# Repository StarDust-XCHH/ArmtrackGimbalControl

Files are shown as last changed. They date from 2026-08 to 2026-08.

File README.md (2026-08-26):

# ArmtrackGimbalControl

[English](README.md) | [简体中文](README.zh-CN.md)

This standalone two-axis gimbal control repository was extracted from the ArmTrack project. It contains STM32F446RE firmware, Python GUI and CLI host tools, a shared ASCII serial protocol, and the UART driver used between the STM32 and two F32C motor controllers.

The repository retains only gimbal control, feedback, HOME, safe stop, and serial integration features. Vision, K230, lower-controller TI communication, shooting, laser calibration, WS2812, and SPI2 application logic are outside its scope.

## Demo Video

https://github.com/user-attachments/assets/8bc28364-a470-4b7c-a2cc-7c203f864003

## 3D Mechanical Model

The STL holder for the STM32, F32C gimbal driver, and power-related boards is archived under [`hardware/3d-models/stm32-f32c-gimbal-holder-v1/`](hardware/3d-models/stm32-f32c-gimbal-holder-v1/). That directory contains the STL, a PNG rendered from the real mesh, clockwise numbering for the four brackets as seen from the closed-face reference view, and a separate CC BY 4.0 license for the mechanical files. The largest bracket can be adapted for a power module; verify hole spacing and clearance against the physical boards before printing.

## Project Structure

```text
ArmtrackGimbalControl/
├── APP/
│   ├── arm/                    # Two-axis control, HOME state machine, angle conversion
│   ├── comm2motor/             # F32C UART frames, BCC, feedback, motor modes
│   └── debug/                  # USART2 text protocol, command parsing, status output
├── Core/
│   ├── Inc/                    # CubeMX/HAL and FreeRTOS headers
│   └── Src/                    # Clock, GPIO, USART, interrupts, task startup
├── Drivers/
│   ├── STM32F4xx_HAL_Driver/   # STM32F4 HAL, with upstream license
│   └── CMSIS/                  # CMSIS core and RTOS interfaces
├── Middlewares/
│   └── Third_Party/FreeRTOS/   # FreeRTOS kernel, with upstream license
├── tools/
│   ├── gimbal_protocol.py      # Shared Python protocol, validation, status parsing
│   ├── gimbal_gui.py           # Tkinter graphical host controller
│   └── gimbal_cli.py           # CLI control and serial diagnostics
├── tests/
│   └── test_protocol.py        # Python protocol unit tests
├── docs/
│   └── demo/
│       └── armtrack-gimbal-demo.mp4  # Compressed integration demo
├── hardware/
│   └── 3d-models/
│       └── stm32-f32c-gimbal-holder-v1/
│           ├── *.stl            # Printable mechanical model
│           ├── *-preview.png    # Rendered STL preview
│           ├── README.md        # Bracket numbering, dimensions, print notes
│           └── LICENSE          # CC BY 4.0 for mechanical assets
├── cmake/
│   ├── gcc-arm-none-eabi.cmake # ARM GCC toolchain configuration
│   └── stm32cubemx/            # CubeMX CMake integration
├── CMakeLists.txt              # Firmware target and source organization
├── CMakePresets.json           # Debug and Release presets
├── ArmtrackGimbalControl.ioc   # STM32CubeMX peripheral/GPIO configuration
├── STM32F446XX_FLASH.ld        # STM32F446RE linker script
├── startup_stm32f446xx.s       # Cortex-M4 startup assembly
├── requirements.txt            # Python dependency list (pyserial)
└── LICENSE                     # MIT license for firmware and Python code
```

`build/`, `cmake-build-*`, compiler outputs, Python caches, and virtual environments are generated locally and excluded by `.gitignore`; they should not be committed.

## 1. System Architecture

```text
Python GUI/CLI
       |
       | USART2, 115200 8N1
       v
STM32F446RE
       |
       | USART3, shared F32C bus, 115200 8N1
       +------ F32C yaw, address 0x01
       +------ F32C pitch, address 0x02
```

The STM32 firmware runs on FreeRTOS and uses these main tasks:

- `GimbalTask`: two-axis control, HOME state machine, feedback acquisition, speed limiting, and position holding.
- `DebugTask`: receives Python text commands through USART2 and returns acknowledgements and periodic status output.
- Default task: maintains the basic CubeMX/FreeRTOS runtime environment.

The firmware retains two mutexes: `bldcUartMutex` protects the USART3 F32C bus, and `debugUartMutex` protects USART2 output.

## 2. Implemented Features

### 2.1 Gimbal Control

- HOME to the initial pose.
- Yaw speed control.
- Single-axis yaw position control.
- Pitch position control.
- Pitch speed control.
- Combined two-axis speed/position control with `track`.
- Two-axis absolute pose control with `pose`.
- `stop`: read the current feedback and hold both axes at their current positions.
- Periodic yaw/pitch feedback acquisition and status output.
- Pitch soft limits to prevent speed mode from crossing the business-angle range.
- Safe mode transitions for yaw position control and HOME.

### 2.2 HOME Behavior

After power-up, the firmware wakes the F32C controllers and waits approximately 1500 ms. When `home` is executed:

1. Yaw speed is set to zero.
2. Yaw single-turn position mode, speed limit, and target are preloaded while the motor is disabled.
3. The yaw target is resent after approximately 100 ms.
4. The yaw target is confirmed after approximately another 50 ms.
5. Pitch timed single-turn position mode, speed limit, and target are preloaded while the motor is disabled.
6. Yaw and pitch feedback are read every 100 ms.
7. HOME succeeds only when both axis errors are no greater than 2.0 degrees for three consecutive stable samples.
8. If this condition is not met within 15 seconds, the firmware enters `HOME FAULT`.

After HOME succeeds, both axes remain in position-hold mode; the firmware does not automatically enter vision control. The normal HOME target is yaw `130.0°` and pitch `330.0°`. During HOME, the firmware reports feedback validity, current angles, and F32C UART error codes so that a motor-position problem can be distinguished from a bus with no feedback.

### 2.3 Angle Conventions

- Yaw business range: `0.0°` to `359.9°`.
- Pitch business range: `230.0°` to `405.0°`.
- Pitch motor angles remain single-turn values. Business angles from `360.0°` to `405.0°` are converted to motor angles from `0.0°` to `45.0°`; feedback is converted back to the continuous business range.
- Internal angle units are 0.1 degrees; for example, `330.0°` is represented as `3300`.

## 3. F32C Driver Implementation

[`APP/comm2motor/Src/bldc_motor.c`](APP/comm2motor/Src/bldc_motor.c) and [`APP/comm2motor/Inc/bldc_motor.h`](APP/comm2motor/Inc/bldc_motor.h) preserve the current implementation from the source project, including:

- Frame header `0x7A`, frame tail `0x7B`, and XOR BCC validation.
- Yaw address `0x01` and pitch address `0x02`.
- Speed, multi-turn position, timed single-turn position, and direct single-turn position modes.
- Enable, disable, speed, position, and feedback operations.
- Feedback-frame timeout and UART error recording.
- Approximately 2 ms spacing between bus commands.
- Power-on wake byte and 1500 ms motor-controller startup delay.

The main driver APIs used by the application are:

```c
BLDC_GimbalPowerOnWake();
BLDC_GimbalStartYawSpeed();
BLDC_GimbalArmYawSingleAngle();
BLDC_GimbalRefreshYawSingleAngle();
BLDC_GimbalStartPitchPosition();
BLDC_GimbalArmPitchPosition();
BLDC_GimbalStartPitchSpeed();
BLDC_GimbalRefreshPitchSpeed();
BLDC_RequestFeedbackValue();
```

The application does not expose the low-level `BLDC_SetSingleAngle()` transition directly for yaw position commands. It uses `Gimbal_SetYawTarget()` to stop the motor, preload while disabled, re-enable it, and confirm the target according to the safe timing sequence.

## 4. Python GUI Usage

### 4.1 Install Dependencies

Python 3.10 or newer is recommended. Ensure that Tkinter is available, then run this command from the repository root:

```powershell
python -m pip install -r requirements.txt
```

`requirements.txt` currently contains only `pyserial`.

### 4.2 Start the GUI

```powershell
python tools/gimbal_gui.py
```

The GUI contains these areas:

- `Serial`: port selection, port refresh, connect/disconnect, HOME, and STOP.
- `Commands`: yaw speed, yaw position, pitch position, pitch speed, `track`, `pose`, and custom commands.
- `Status`: current angles, target angles, HOME status, and operating state.
- Log area: serial transmit/receive data, status lines, heartbeat responses, and errors.

### 4.3 Recommended Operating Procedure

1. Connect the STM32, USB-to-serial adapter, and F32C motor bus according to the wiring section.
2. Power the STM32 and motor controllers, ensuring that the mechanism can be powered off safely.
3. Start the GUI.
4. Click `Refresh` and confirm the USB-to-serial COM port in the port field.
5. Click `Connect / Disconnect` to establish the connection.
6. Confirm that `TOCK` responses and periodic status lines appear in the log.
7. Click `HOME`, wait for `GIMBAL HOME OK`, and confirm `homed:1` and `home_fault:0`.
8. Send position or speed commands only after HOME succeeds.
9. When testing is complete, click `STOP`, confirm both axes hold their current positions, and then disconnect motor power.

After connecting, the GUI sends one `tick` heartbeat every second. The heartbeat checks USART2 communication only and does not drive the motors.

### 4.4 GUI Controls

| Control | Input range | Command | Purpose |
| --- | --- | --- | --- |
| Yaw speed rpm | `-100` to `100` | `yaw <rpm>` | Yaw speed control; `0` stops yaw speed |
| Yaw position | `0.0` to `359.9` | `yawpos <angle>` | Controls yaw position only and preserves the pitch target |
| Pitch position | `230.0` to `405.0` | `pitch <angle>` | Pitch business-angle position control |
| Pitch speed rpm | `-30` to `30` | `pitchspd <rpm>` | Pitch speed control with soft limits |
| Track yaw rpm / pitch | yaw `-100..100`, pitch `230..405` | `track <yaw_rpm> <pitch>` | Combined yaw speed and pitch position control |
| Pose yaw / pitch | yaw `0..359.9`, pitch `230..405` | `pose <yaw> <pitch>` | Two-axis position control |
| HOME | None | `home` | Runs the HOME state machine |
| STOP | None | `stop` | Holds the current feedback positions of both axes |
| Send custom | ASCII text | Custom | Sends an allowed protocol command |

Angle fields accept `330`, `330.0`, and `x3300`. Both the firmware and Python protocol module convert angles to 0.1-degree units and round to the nearest 0.1 degree.

### 4.5 Status Fields

The GUI status area is populated from periodic STM32 text lines such as:

```text
yaw_cur:130.0,yaw_tgt:130.0,pitch_cur:330.0,pitch_tgt:330.0,homed:1,home_fault:0,state:3
```

- `yaw_cur`: current yaw feedback angle, or `NA` when feedback is unavailable.
- `yaw_tgt`: current yaw target angle, or `NA` in speed mode.
- `pitch_cur`: current pitch feedback angle, or `NA` when feedback is unavailable.
- `pitch_tgt`: current pitch business-angle target.
- `homed`: `1` means HOME succeeded; `0` means it has not succeeded.
- `home_fault`: `1` means HOME timed out.
- `state`: `0` means HOMING, `3` means manual control, and `4` means HOME fault.

### 4.6 GUI Troubleshooting

- The port field shows `none`: no serial port was detected. Check the USB-to-serial driver, USB connection, and COM port in Device Manager.
- The GUI connects but receives no `TOCK`: check that TX/RX are crossed, all devices share ground, and USART2 is actually routed to PA2/PA3.
- `TOCK` works but no F32C feedback is received: check USART3 wiring, motor power, common ground, 3.3 V logic compatibility, and F32C addresses.
- HOME enters fault: check F32C bus feedback first, then verify the physical yaw/pitch directions and mechanical range. Do not repeatedly send high-speed commands.
- A position command is rejected: confirm that the requested angle or speed is within the table limits.

## 5. CLI Usage

The CLI supports scripted tests, field diagnostics, and systems without a graphical desktop:

```powershell
python tools/gimbal_cli.py --port COM34
```

Send one or more commands:

```powershell
python tools/gimbal_cli.py --port COM34 --no-hex --command "home" --command "yawpos 130.0"
```

Listen for 10 seconds and send heartbeats:

```powershell
python tools/gimbal_cli.py --port COM34 --duration 10 --heartbeat --no-hex
```

The default baud rate is 115200 and can be changed with `--baud`. Received data is shown in hexadecimal by default; use `--no-hex` to disable it.

## 6. USART2 Text Protocol

All commands are ASCII text terminated by `CR/LF` (`\r\n`).

| Command | Range / format | Response or action |
| --- | --- | --- |
| `tick <seq>` | Non-negative 32-bit integer | Returns `TOCK <seq> <uptime_ms>` |
| `home` | No argument | HOME to yaw `130.0°`, pitch `330.0°` |
| `stop` | No argument | Stops current motion and holds the current position |
| `yaw <rpm>` | `-100..100` | Yaw speed control |
| `yawpos <angle>` | `0..359.9` | Single-axis yaw position control |
| `pitch <angle>` | `230..405` | Pitch position control |
| `pitchspd <rpm>` | `-30..30` | Pitch speed control |
| `track <yaw_rpm> <pitch>` | `-100..100`, `230..405` | Yaw speed plus pitch position |
| `pose <yaw> <pitch>` | `0..359.9`, `230..405` | Two-axis position control |

Removed legacy application commands such as `auto`, `vision`, `material`, `target`, `laser`, `vpid`, `left`, and `right` are not accepted.

## 7. Wiring

### 7.1 Python Host to STM32 USART2

Use a 3.3 V TTL USB-to-serial adapter. TX and RX must be crossed:

| USB-to-serial | STM32F446RE | Description |
| --- | --- | --- |
| TX | PA3 / `USART2_RX` | Host transmit to STM32 receive |
| RX | PA2 / `USART2_TX` | STM32 transmit to host receive |
| GND | GND | Common ground is required |

USART2 uses `115200 baud, 8 data bits, no parity, 1 stop bit` (115200 8N1). Do not connect RS-232 ±12 V signals directly to the STM32, and do not connect the USB-to-serial adapter to the USART3 motor bus.

### 7.2 STM32 to F32C Motor Bus on USART3

| STM32F446RE | F32C bus | Description |
| --- | --- | --- |
| PB10 / `USART3_TX` | F32C RX | STM32 transmits bus frames |
| PC5 / `USART3_RX` | F32C TX | STM32 receives feedback frames |
| GND | F32C GND | Common ground is required |

USART3 also uses `115200 8N1`. Yaw and pitch share the bus and are distinguished by F32C address: yaw is `0x01`, and pitch is `0x02`. Supply the motor and STM32 logic power according to the actual hardware design, and verify compatible logic levels.

### 7.3 Board GPIO

The project retains the original board configuration:

- PA5: onboard green LED.
- PC13: onboard push-button input.
- PA13/PA14: SWD debug interface.
- PB3: SWO.
- External clock and LSE settings remain as configured in the CubeMX project.

The LED and button remain in the board configuration, but the standalone application does not depend on an LED or button task.

## 8. Firmware Build and Flashing

### 8.1 Build Environment

Install STM32CubeCLT or an equivalent `arm-none-eabi-gcc` toolchain, CMake 3.22 or newer, and Ninja. STM32F4 HAL, CMSIS, and FreeRTOS are included in the repository.

### 8.2 Debug and Release Builds

Run these commands from the repository root:

```powershell
cmake --preset Debug
cmake --build --preset Debug

cmake --preset Release
cmake --build --preset Release
```

The primary firmware outputs are located at:

```text
build/Debug/ArmtrackGimbalControl.elf
build/Release/ArmtrackGimbalControl.elf
```

Use STM32CubeProgrammer, STM32CubeIDE, or another STM32F446RE-compatible tool to flash the ELF or converted BIN/HEX through ST-LINK. Confirm the MCU model, target power, and debug wiring before flashing.

## 9. Testing

Run the Python syntax check and protocol unit tests with:

```powershell
python -m compileall -q tools tests
python -m unittest discover -s tests -v
```

The current tests cover valid and out-of-range angles, the `xNNNN` format, rounding of multi-decimal input, speed boundaries, command formatting, `tick`/`TOCK` heartbeats, and status-line parsing.

Hardware integration testing should verify USART2 command exchange, USART3 yaw/pitch feedback, HOME success and 15-second timeout, `yawpos` preserving the pitch target, `stop` position holding, and the ranges and timing of every single-axis and dual-axis command.

## 10. Safety Notes

- Perform the first power-up and HOME test unloaded or in a low-risk setup, and verify direction and mechanical limits.
- Do not rely on position feedback before HOME succeeds.
- Keep an emergency power cutoff accessible during testing.
- Near pitch business limits `230.0°` and `405.0°`, speed mode triggers the soft limit and sets speed to zero.
- `stop` holds the current position; it does not disconnect motor power. Use hardware power cutoff first during an abnormal condition.
- Never mix the USART2 host wiring with the USART3 F32C bus.

## 11. Licensing

New application code in this repository is released under the MIT License; see [LICENSE](LICENSE). STM32 HAL, CMSIS, and FreeRTOS retain their original upstream licenses and copyright notices.

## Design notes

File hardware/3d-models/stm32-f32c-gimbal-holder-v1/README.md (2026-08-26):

# STM32 / F32C Gimbal Holder v1

这是用于本项目双轴云台、STM32F446RE 控制板和配套驱动板的 3D 安装支架。模型以 STL 二进制格式提供，适合直接导入切片软件进行打印或作为装配参考。

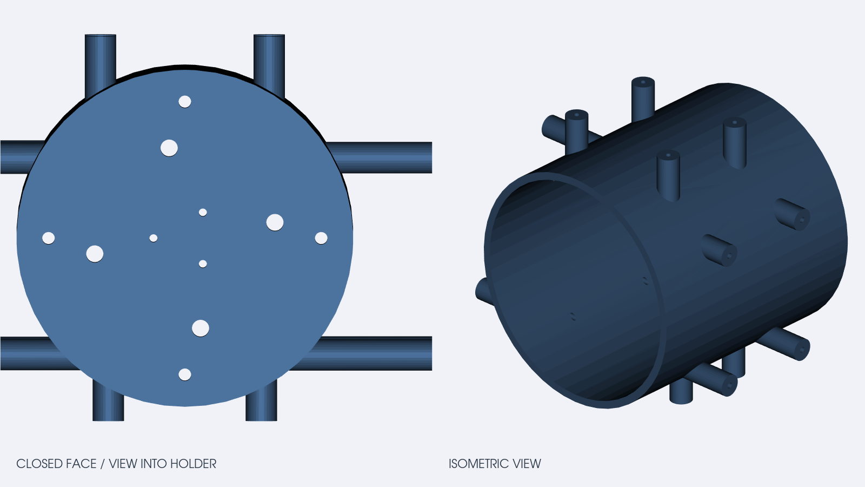
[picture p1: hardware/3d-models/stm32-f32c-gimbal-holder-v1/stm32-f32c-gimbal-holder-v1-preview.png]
STL preview


## 文件

- `stm32-f32c-gimbal-holder-v1.stl`：可打印的 STL 网格。
- `stm32-f32c-gimbal-holder-v1-preview.png`：从真实 STL 网格渲染的预览图。左图为从最大中间圆柱支撑架的封口圆面朝开口方向观察的基准视角，右图为等轴视图。

## 装配方向和挂架编号

从最大中间圆柱支撑架的封口面向下（朝开口方向）观察，沿顺时针方向按装配约定编号如下：

| 编号 | 挂架形式 | 设计用途 | 备注 |
| --- | --- | --- | --- |
| 1 | 三孔 | STM32F446RE 挂架 | 安装主控板 |
| 2 | 四孔，最小 | 云台驱动板挂架 | 安装 F32C/云台驱动板 |
| 3 | 四孔，最大 | 特定需求的裁判板挂架 | 可按实际尺寸改为电源模块挂架 |
| 4 | 四孔，中等 | 电源驱动板挂架 | 安装配套电源驱动板 |

编号描述的是封口面视角下的相对顺序；整体旋转模型后，编号随模型一起旋转，不代表 STL 世界坐标中的固定方位。

## 几何信息

- 包围盒尺寸约为 `110 x 90 x 97.9 mm`（X x Y x Z）。
- STL 按毫米理解；导入切片软件后请确认单位未被自动缩放。
- 网格为封闭（watertight）三角网格，可作为打印输入。
- STL 不包含可编辑的 STEP、原生 CAD 或参数化孔位；如需改板卡孔距，建议在此基础上补充可编辑 CAD 源文件。

## 打印和装配建议

以下仅是起始参数，不是已经验证的制造规范：

- PLA 或 PETG；先在目标打印机上确认材料收缩和层间强度。
- 层高可从 `0.20 mm` 开始，外壳 `3-4` 圈，填充率 `25-40%` 作为初始尝试。
- 按切片软件的悬垂和桥接分析决定摆放方向及支撑，不要直接假定预览图方向就是最佳打印方向。
- 打印前用实际板卡、铜柱和紧固件核对孔距、净空、螺钉长度及线缆出口；首次装配建议低速、断电可及。

## 许可

本目录中的机械模型和预览图按 [CC BY 4.0](LICENSE) 发布。再分发或修改时请保留作者和本仓库链接，并在改版文件中注明修改内容。仓库中的固件和 Python 代码使用根目录的 MIT License，两者许可范围不同。

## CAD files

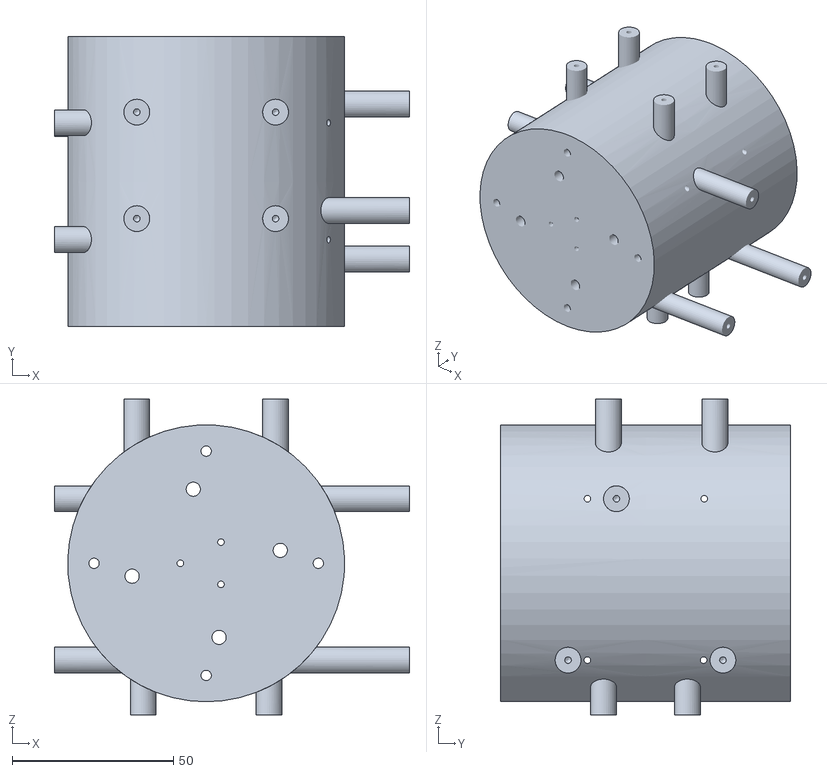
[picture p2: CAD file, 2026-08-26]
hardware/3d-models/stm32-f32c-gimbal-holder-v1/stm32-f32c-gimbal-holder-v1.stl
110.0 x 90.0 x 97.9

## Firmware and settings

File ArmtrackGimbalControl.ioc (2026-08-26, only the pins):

Mcu.UserName=STM32F446RETx
PA13.GPIO_Label=TMS
PA13.Signal=SYS_JTMS-SWDIO
PA14.GPIO_Label=TCK
PA14.Signal=SYS_JTCK-SWCLK
PA2.GPIO_Label=USART_TX
PA2.Signal=USART2_TX
PA3.GPIO_Label=USART_RX
PA3.Signal=USART2_RX
PA5.GPIO_Label=LD2 [Green Led]
PA5.Signal=GPIO_Output
PB3.GPIO_Label=SWO
PB3.Signal=SYS_JTDO-SWO
PB10.Signal=USART3_TX
PC13.GPIO_Label=B1 [Blue PushButton]
PC13.Signal=GPXTI13
PC14-OSC32_IN.Signal=RCC_OSC32_IN
PC15-OSC32_OUT.Signal=RCC_OSC32_OUT
PC5.Signal=USART3_RX
PH0-OSC_IN.Signal=RCC_OSC_IN
PH1-OSC_OUT.Signal=RCC_OSC_OUT

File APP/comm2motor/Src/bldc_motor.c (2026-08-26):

#include "bldc_motor.h"

#include <string.h>

#include "cmsis_os.h"
#include "usart.h"

#define BLDC_HEADER 0x7AU
#define BLDC_TAIL   0x7BU

#define BLDC_CMD_MODE    0x00U
#define BLDC_CMD_SPEED   0x01U
#define BLDC_CMD_POSITION 0x02U
#define BLDC_CMD_SINGLE_POS_LEGACY 0x03U
#define BLDC_CMD_DISABLE 0x05U
#define BLDC_CMD_ENABLE  0x06U
#define BLDC_CMD_ACC     0x07U
#define BLDC_CMD_FEEDBACK 0x0EU

#define BLDC_TX_TIMEOUT_MS 20U
#define BLDC_FEEDBACK_VALUE_FIRST_BYTE_TIMEOUT_MS 12U
#define BLDC_FEEDBACK_VALUE_NEXT_BYTE_TIMEOUT_MS  5U
#define BLDC_FEEDBACK_FRAME_LEN 9U
#define BLDC_CMD_GAP_MS     2U
#define BLDC_POWER_ON_DELAY_MS 1500U
#define BLDC_STARTUP_RETRY_COUNT 3U
#define BLDC_STARTUP_RETRY_DELAY_MS 100U
#define BLDC_POSITION_LEGACY_FALLBACK_ENABLE 0U

extern osMutexId_t bldcUartMutexHandle;

static uint32_t bldc_last_uart_error = HAL_UART_ERROR_NONE;
static volatile uint8_t bldc_startup_attempt_count;
static volatile uint8_t bldc_startup_yaw_feedback_ok;
static volatile uint8_t bldc_startup_pitch_feedback_ok;

static void bldc_flush_uart_rx(void)
{
  uint32_t ignored;

  __HAL_UART_CLEAR_OREFLAG(&huart3);

  while (__HAL_UART_GET_FLAG(&huart3, UART_FLAG_RXNE) != RESET)
  {
    ignored = huart3.Instance->DR;
    (void)ignored;
  }
}

static uint8_t bldc_calc_bcc(const uint8_t *data, uint8_t len)
{
  uint8_t bcc = 0U;

  for (uint8_t i = 0U; i < len; i++)
  {
    bcc ^= data[i];
  }

  return bcc;
}

static uint8_t bldc_build_cmd(uint8_t addr,
                              uint8_t cmd,
                              const uint8_t *data,
                              uint8_t len,
                              uint8_t *tx_buf,
                              uint8_t tx_buf_size)
{
  uint8_t idx = 0U;

  if ((tx_buf == NULL) || (tx_buf_size < (uint8_t)(len + 5U)))
  {
    return 0U;
  }

  tx_buf[idx++] = BLDC_HEADER;
  tx_buf[idx++] = addr;
  tx_buf[idx++] = cmd;

  if ((data != NULL) && (len > 0U))
  {
    memcpy(&tx_buf[idx], data, len);
    idx = (uint8_t)(idx + len);
  }

  tx_buf[idx] = bldc_calc_bcc(tx_buf, idx);
  idx++;
  tx_buf[idx++] = BLDC_TAIL;

  return idx;
}

static void bldc_send_array(const uint8_t *data, uint8_t len)
{
  HAL_StatusTypeDef result;

  if (bldcUartMutexHandle != NULL)
  {
    (void)osMutexAcquire(bldcUartMutexHandle, osWaitForever);
  }

  result = HAL_UART_Transmit(&huart3, (uint8_t *)data, len, BLDC_TX_TIMEOUT_MS);
  if (result != HAL_OK)
  {
    bldc_last_uart_error = HAL_UART_GetError(&huart3);
    if (bldc_last_uart_error == HAL_UART_ERROR_NONE)
    {
      bldc_last_uart_error = HAL_UART_ERROR_DMA;
    }
  }
  else
  {
    bldc_last_uart_error = HAL_UART_ERROR_NONE;
  }

  if (bldcUartMutexHandle != NULL)
  {
    (void)osMutexRelease(bldcUartMutexHandle);
  }
}

static void bldc_send_legacy_single_angle(uint8_t addr, uint16_t angle_x10)
{
  uint8_t data[2];

  if (angle_x10 > 3599U)
  {
    angle_x10 = 3599U;
  }

  data[0] = (uint8_t)((angle_x10 >> 8) & 0xFFU);
  data[1] = (uint8_t)(angle_x10 & 0xFFU);
  BLDC_SendCmd(addr, BLDC_CMD_SINGLE_POS_LEGACY, data, sizeof(data));
}

static uint8_t bldc_request_feedback_frame(uint8_t addr,
                                           uint8_t type,
                                           uint8_t *rx_buf,
                                           uint8_t rx_buf_size,
                                           uint32_t first_byte_timeout_ms,
                                           uint32_t next_byte_timeout_ms)
{
  uint8_t tx_buf[6];
  uint8_t data[1];
  uint8_t tx_len;
  uint8_t rx_len = 0U;

  if ((rx_buf == NULL) || (rx_buf_size == 0U))
  {
    return 0U;
  }

  data[0] = type;
  tx_len = bldc_build_cmd(addr,
                          BLDC_CMD_FEEDBACK,
                          data,
                          sizeof(data),
                          tx_buf,
                          sizeof(tx_buf));
  if (tx_len == 0U)
  {
    return 0U;
  }

  bldc_last_uart_error = HAL_UART_ERROR_NONE;
  bldc_flush_uart_rx();

  if (bldcUartMutexHandle != NULL)
  {
    (void)osMutexAcquire(bldcUartMutexHandle, osWaitForever);
  }

  if (HAL_UART_Transmit(&huart3, tx_buf, tx_len, BLDC_TX_TIMEOUT_MS) == HAL_OK)
  {
    uint32_t wait_start = HAL_GetTick();

    while (rx_len < rx_buf_size)
    {
      if (__HAL_UART_GET_FLAG(&huart3, UART_FLAG_RXNE) != RESET)
      {
        rx_buf[rx_len] = (uint8_t)(huart3.Instance->DR & 0xFFU);
        rx_len++;
        wait_start = HAL_GetTick();

        if ((rx_buf_size != BLDC_FEEDBACK_FRAME_LEN) &&
            (rx_len >= 5U) &&
            (rx_buf[rx_len - 1U] == BLDC_TAIL))
        {
          break;
        }
      }
      else
      {
        uint32_t timeout = (rx_len == 0U) ? first_byte_timeout_ms : next_byte_timeout_ms;

        if ((HAL_GetTick() - wait_start) >= timeout)
        {
          break;
        }
      }
    }
  }
  else
  {
    bldc_last_uart_error = HAL_UART_GetError(&huart3);
  }

  if (HAL_UART_GetError(&huart3) != HAL_UART_ERROR_NONE)
  {
    bldc_last_uart_error = HAL_UART_GetError(&huart3);
  }

  if (bldcUartMutexHandle != NULL)
  {
    (void)osMutexRelease(bldcUartMutexHandle);
  }

  return rx_len;
}

void BLDC_SendCmd(uint8_t addr, uint8_t cmd, const uint8_t *data, uint8_t len)
{
  uint8_t tx_buf[20];
  uint8_t tx_len;

  if (len > 14U)
  {
    return;
  }

  tx_len = bldc_build_cmd(addr, cmd, data, len, tx_buf, sizeof(tx_buf));
  if (tx_len > 0U)
  {
    bldc_send_array(tx_buf, tx_len);
  }
}

void BLDC_Enable(uint8_t addr)
{
  BLDC_SendCmd(addr, BLDC_CMD_ENABLE, NULL, 0U);
}

void BLDC_Disable(uint8_t addr)
{
  BLDC_SendCmd(addr, BLDC_CMD_DISABLE, NULL, 0U);
}

void BLDC_SetMode(uint8_t addr, uint16_t mode)
{
  uint8_t data[2];

  data[0] = (uint8_t)((mode >> 8) & 0xFFU);
  data[1] = (uint8_t)(mode & 0xFFU);
  BLDC_SendCmd(addr, BLDC_CMD_MODE, data, sizeof(data));
}

void BLDC_SetSpeed(uint8_t addr, int16_t rpm)
{
  uint8_t data[2];
  uint16_t raw = (uint16_t)rpm;

  data[0] = (uint8_t)((raw >> 8) & 0xFFU);
  data[1] = (uint8_t)(raw & 0xFFU);
  BLDC_SendCmd(addr, BLDC_CMD_SPEED, data, sizeof(data));
}

void BLDC_SetPosition(uint8_t addr, int32_t angle_x10)
{
  uint8_t data[4];
  uint32_t raw = (uint32_t)angle_x10;

  data[0] = (uint8_t)((raw >> 24) & 0xFFU);
  data[1] = (uint8_t)((raw >> 16) & 0xFFU);
  data[2] = (uint8_t)((raw >> 8) & 0xFFU);
  data[3] = (uint8_t)(raw & 0xFFU);
  BLDC_SendCmd(addr, BLDC_CMD_POSITION, data, sizeof(data));

#if BLDC_POSITION_LEGACY_FALLBACK_ENABLE
  if ((angle_x10 >= 0) && (angle_x10 <= 3600L))
  {
    osDelay(BLDC_CMD_GAP_MS);
    bldc_send_legacy_single_angle(addr, (uint16_t)angle_x10);
  }
#endif
}

void BLDC_SetSingleAngle(uint8_t addr, uint16_t angle_x10)
{
  if (angle_x10 > 3599U)
  {
    angle_x10 = 3599U;
  }

  bldc_send_legacy_single_angle(addr, angle_x10);
}

void BLDC_SetAcc(uint8_t addr, uint16_t acc)
{
  uint8_t data[2];

  data[0] = (uint8_t)((acc >> 8) & 0xFFU);
  data[1] = (uint8_t)(acc & 0xFFU);
  BLDC_SendCmd(addr, BLDC_CMD_ACC, data, sizeof(data));
}
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

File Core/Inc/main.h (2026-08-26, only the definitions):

#define B1_Pin GPIO_PIN_13
#define B1_GPIO_Port GPIOC
#define USART_TX_Pin GPIO_PIN_2
#define USART_TX_GPIO_Port GPIOA
#define USART_RX_Pin GPIO_PIN_3
#define USART_RX_GPIO_Port GPIOA
#define F32C_TX_Pin GPIO_PIN_10
#define F32C_TX_GPIO_Port GPIOB
#define F32C_RX_Pin GPIO_PIN_5
#define F32C_RX_GPIO_Port GPIOC
#define LD2_Pin GPIO_PIN_5
#define LD2_GPIO_Port GPIOA
#define TMS_Pin GPIO_PIN_13
#define TMS_GPIO_Port GPIOA
#define TCK_Pin GPIO_PIN_14
#define TCK_GPIO_Port GPIOA
#define SWO_Pin GPIO_PIN_3
#define SWO_GPIO_Port GPIOB

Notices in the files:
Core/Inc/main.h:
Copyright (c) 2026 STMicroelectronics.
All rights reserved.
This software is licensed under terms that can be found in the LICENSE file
